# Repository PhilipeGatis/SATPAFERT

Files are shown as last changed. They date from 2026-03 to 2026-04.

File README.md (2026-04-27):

<p align="center">
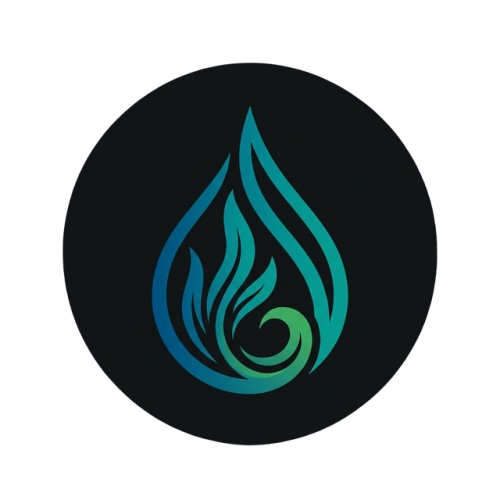
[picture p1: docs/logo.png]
IARA Logo
  
</p>

# IARA

**Automated Water Change, Fertilization & Filtration System for Aquariums** — ESP32 firmware.

*Named after Iara, the freshwater spirit from Brazilian folklore.*



> 🇧🇷 Leia em português: [README.pt-BR.md](README.pt-BR.md)
>
> 🇯🇵 日本語で読む: [README.ja.md](README.ja.md)

---

## 📖 About

**IARA** is a complete embedded system for planted aquarium automation. It manages:

- **Water Change (TPA)** — automated drain & refill with a 6-state state machine.
- **Fertilization** — scheduled dosing via peristaltic pumps with stock tracking.
- **Filtration** — canister on/off control through an SSR relay (AC power).
- **Safety** — continuous sensor monitoring, watchdog timer, and emergency shutdown mode.

The firmware runs on an **ESP32 DevKit V1** and features an **embedded web dashboard** (React + Vite served via LittleFS), **color TFT display (ST7735)**, **DS3231 RTC clock**, and a **serial command interface**.

---

## 📚 Additional Documentation

The project includes detailed hardware documentation in the following files:

| Document | Description |
|---|---|
| [`BOM.md`](BOM.md) | **Bill of Materials** — complete list of all components required for assembly, organized by layer (AC, DC, actuators, sensors, protection, and connectors), with specifications and quantities. |
| [`HARDWARE.md`](HARDWARE.md) | **Hardware Architecture** — detailed technical documentation with wiring diagrams for each layer (AC input, DC bus, and peripherals), including noise protection schemes, voltage dividers for sensors, and safety implementation notes. |
| [`3d_models/`](3d_models/) | **3D Models (OpenSCAD)** — parametric electronics enclosure (`electronics_enclosure.scad`) with full module layout, dosing pump supports (`dosing_pump_support.scad` / `dosing_pump_single.scad`), and drill test plate for verification. |

---

## 🏗️ Firmware Architecture

```
main.cpp               ← Main orchestrator
├── SafetyWatchdog      ← Sensors + emergency + maintenance mode
├── TimeManager         ← DS3231 RTC + NTP sync
├── FertManager         ← Dosing + NVS dedup + stock tracking
├── WaterManager        ← Water change state machine (6 states)
├── DisplayManager      ← TFT ST7735 128×160 (SPI)
└── WebManager          ← Embedded web dashboard + serial interface
```

### Safety-First Loop

```cpp
loop() {
    safety.update();          // 🔴 Highest priority
    if (emergency) return;
    timeMgr.update();
    commands.process();
    schedules.check();
    waterMgr.update();        // Water change state machine
    telemetry.send();
}
```

### 🔄 Water Change (TPA) Flow

The TPA is a 6-state state machine that runs non-blocking inside the main loop. Each state has a configurable timeout for safety.

```mermaid
stateDiagram-v2
    [*] --> CANISTER_OFF: startTPA()
    CANISTER_OFF --> DRAINING: 3s settle
    DRAINING --> FILLING_RESERVOIR: level reached
    FILLING_RESERVOIR --> DOSING_PRIME: float switch
    DOSING_PRIME --> REFILLING: 2s mix
    REFILLING --> CANISTER_ON: level reached
    CANISTER_ON --> [*]: COMPLETE

    DRAINING --> ERROR: timeout
    FILLING_RESERVOIR --> ERROR: timeout
    REFILLING --> ERROR: timeout / optical sensor
    ERROR --> [*]: check level → canister ON/OFF
```

| Step | State | What happens |
|---|---|---|
| 1 | **CANISTER_OFF** | Canister filter is turned off (SSR relay HIGH). Waits 3 seconds for water to settle so the ultrasonic sensor gets a stable reading. |
| 2 | **DRAINING** | Drain pump turns on. Ultrasonic sensor monitors the water level. Pump runs until the target level is reached (e.g. 10 cm drop). Flow rate is measured inline for auto-calibration. |
| 3 | **FILLING_RESERVOIR** | Solenoid valve opens to fill the reservoir with tap water. Float switch monitors reservoir level. Valve closes when reservoir is full. |
| 4 | **DOSING_PRIME** | Peristaltic pump doses dechlorinator (Prime) into the reservoir. Waits 2 seconds for mixing. Stock level is deducted and saved to NVS. |
| 5 | **REFILLING** | Refill pump turns on, pumping treated water from reservoir into the aquarium. Stops when ultrasonic sensor reaches the original level OR optical sensor detects max level (safety cutoff). Flow rate is measured for calibration. |
| 6 | **CANISTER_ON** | Canister filter is turned back on. **TPA cycle complete.** Calibrated flow rates are saved to NVS for next TPA. |

**Safety at every step:**
- Each state has a **dynamic timeout** calculated from calibrated flow rates (`volume / flow × 1.5`). First TPA uses safe defaults: **30s drain, 15s refill**.
- The **optical sensor** acts as a hardware-level safety cutoff during refill — immediate stop regardless of ultrasonic reading.
- **Emergency abort** at any point turns off all actuators and restores the canister filter.
- **On error**, the system checks the water level via ultrasonic before turning the canister back on. If the level is too low (e.g. error during drain), the canister **stays OFF** to avoid running dry and damaging the pump.

---

## 🔌 Hardware Overview

### Main Connections

```mermaid
graph LR
  subgraph Power [⚡ 12V & 5V]
    PSU[12V PSU] -->|12V| MOSFET[8-Channel MOSFET Module]
    PSU -->|12V| LM2596[LM2596 Step Down]
    LM2596 -->|5V| Cap[Electrolytic Capacitor]
    Cap -->|5V| ESP32[ESP32 VIN]
    Cap -->|5V VCC| SENS[Sensors]
  end

  subgraph Signals [🎮 ESP32 Signals]
    ESP32 -->|D21 SDA, D22 SCL| I2C[RTC DS3231]
    ESP32 -->|SPI D15,16,17,23| TFT[TFT Display ST7735]
    ESP32 -->|D12, D13, D14, D25-D27, D32, D33| MOSFET
    ESP32 -->|D2| SSR[Omron SSR]
    ESP32 ---|D18 Trig, D34 Echo| Ultra[Ultrasonic JSN]
    ESP32 ---|D4| Water[Capacitive Sensor]
    ESP32 ---|D5| Float[Float Switch]
    ESP32 ---|D19| Button[Button]
  end

  MOSFET -->|OUT 1–5| Peristaltic[5x Peristaltic Pumps]
  MOSFET -->|OUT 6| Drain[Drain Pump]
  MOSFET -->|OUT 7| Refill[Refill Pump]
  MOSFET -->|OUT 8| Solenoid[Solenoid Valve]
```

> For detailed wiring diagrams, voltage dividers, and protection notes (flyback diodes, star GND), see [`HARDWARE.md`](HARDWARE.md).
>
> For the complete component list and quantities, see [`BOM.md`](BOM.md).

### ESP32 GPIO Connection Diagram

| GPIO | Function | Component | Direction | Protocol |
|---|---|---|---|---|
| **D2** | Canister ON/OFF | Omron SSR Relay | Output | Digital |
| **D4** | Max level sensor | XKC-Y25-NPN (capacitive) | Input (PULLUP) | Digital |
| **D5** | Reservoir float | Horizontal Float Switch | Input (PULLUP) | Digital |
| **D12** | Fertilizer CH2 | MOSFET channel 2 | Output | Digital |
| **D13** | Fertilizer CH1 | MOSFET channel 1 | Output | Digital |
| **D14** | Fertilizer CH3 | MOSFET channel 3 | Output | Digital |
| **D15** | TFT CS | ST7735 Display (CS) | Output | SPI (CS) |
| **D16** | TFT SCK | ST7735 Display (SCK) | Output | SPI (SCK) |
| **D17** | TFT A0 (Data/Command) | ST7735 Display (A0) | Output | SPI (DC) |
| **D18** | Ultrasonic Trigger | JSN-SR04T | Output | Digital |
| **D19** | Contact button | Push/Tactile Button (Panel) | Input (PULLUP) | Digital |
| **D21** | SDA | DS3231 RTC | Bidirectional | I2C |
| **D22** | SCL | DS3231 RTC | Bidirectional | I2C |
| **D23** | TFT SDA (Data) | ST7735 Display (SDA) | Output | SPI (MOSI) |
| **D25** | Drain pump | MOSFET channel 6 | Output | Digital |
| **D26** | Prime (dechlorinator) | MOSFET channel 5 | Output | Digital |
| **D27** | Fertilizer CH4 | MOSFET channel 4 | Output | Digital |
| **D32** | Solenoid valve | MOSFET channel 8 | Output | Digital |
| **D33** | Refill pump | MOSFET channel 7 | Output | Digital |
| **D34** | Ultrasonic Echo | JSN-SR04T | Input | Digital (3.3V via divider) |
| **VIN** | 5V Power | LM2596 step-down | — | Power |
| **EN** | Shared reset | ST7735 Display (RESET) | — | Reset |
| **3.3V** | Backlight | ST7735 Display (LED) | — | Power |

---

## 🛡️ Safety & Reliability

The system is designed with a **safety-first** approach to prevent flooding, equipment damage, and fish loss.

### Software Protections

| Protection | Description |
|---|---|
| **Hardware Watchdog (WDT)** | ESP32 Task WDT with 10-second timeout. If the main loop freezes for any reason, the ESP32 automatically reboots. |
| **SafetyWatchdog** | Runs at highest priority every loop iteration. Detects overflow (optical sensor), emergency conditions, and triggers full shutdown of all actuators. |
| **Non-blocking loops** | All wait states (canister settle, prime mixing) use `millis()` instead of `delay()`, so the safety watchdog keeps running during waits. |
| **State machine timeouts** | Each TPA state (`DRAINING`, `FILLING`, `REFILLING`) has a configurable timeout. Exceeding it triggers an error state and shuts down all actuators. |
| **NVS deduplication** | Prevents double-dosing fertilizers on the same day, even after unexpected reboots. |
| **Emergency shutdown** | `emergency_stop` command turns off ALL actuators immediately. |
| **CPU throttle** | Main loop runs at ~100 Hz (`delay(10)`), preventing overheating and leaving CPU headroom for WiFi/TCP stack. |
| **Pump auto-calibration** | Flow rates measured inline during TPA (Δlevel × litersPerCm / Δtime). Dynamic timeouts = `(volume / flow) × 1.5`. First TPA uses safe 30s/15s defaults. |
| **Mandatory TPA config** | TPA will not start unless all required parameters are configured: aquarium dimensions, reservoir volume, drain %, and canister safe level %. Prevents running with invalid/default values. |
| **Canister safe level (%)** | Configurable minimum water level (as % of aquarium height) required to safely turn the canister back on after a TPA error. If the water is below this threshold (e.g. error during drain), the canister stays OFF to prevent running dry. |

### Hardware Recommendations

| Protection | Description |
|---|---|
| **Overflow float switch** | NC (normally closed) float switch at max water level, wired in series with the refill pump power. Cuts the pump physically if water rises too high — independent of firmware. |
| **Flyback diodes** | FR154 on pumps, 1N5822 on solenoid — absorb voltage spikes from inductive loads. |
| **Decoupling capacitors** | 1000µF near ESP32, 470µF near MOSFET module — absorb brownout transients. |
| **Voltage divider (ECHO)** | 5V → 3.3V for JSN-SR04T echo pin — protects ESP32 GPIO. |
| **Siphon break (Drain)** | Wire a solenoid valve in parallel with the drain pump (requires its own flyback diode) or make a small breather hole in the hose inside the aquarium to prevent water from continuing to drain by gravity after the pump turns off. |

---

## 📲 Push Notifications

IARA sends real-time push notifications to your phone via [Pushsafer](https://www.pushsafer.com/). Each notification type can be individually enabled or disabled via the dashboard.

### Notification Types

| Type | Trigger | Example Message |
|---|---|---|
| **TPA Complete** | Water change finished successfully | `✅ TPA completed successfully` |
| **TPA Error** | Timeout or failure during TPA | `⚠️ Drain timeout \| Canister: OFF (nivel 45%, min: 60%)` |
| **Fert Low Stock** | Fertilizer stock below threshold | `⚠️ CH1 Potássio: 15 mL remaining (threshold: 50 mL)` |
| **Emergency** | Emergency shutdown triggered | `🚨 Emergency shutdown activated!` |
| **Fert Complete** | Fertilizer dose completed | `💧 CH2 dosed 5.0 mL` |
| **Daily Level** | Scheduled daily water level report | `📊 Water level: 12.3 cm` |

### Rate Limiting

| Parameter | Value |
|---|---|
| Cooldown per type | 5 minutes (same type won't fire twice) |
| Max per day | 20 notifications total |
| Daily counter reset | Midnight (auto) |

### Setup

1. Create a free account at [pushsafer.com](https://www.pushsafer.com/)
2. Copy your **Private Key** from the Pushsafer dashboard
3. Enter the key via IARA dashboard (`Notifications → API Key`) or via API:
   ```bash
   curl -X POST http://<ESP32_IP>/api/notify/key -d '{"key":"YOUR_KEY"}'
   ```
4. Enable/disable specific notification types via the dashboard

---

## ⚙️ System Configuration

Before the first TPA can run, the system requires all safety-critical parameters to be configured. This ensures the water change operates safely for your specific aquarium setup.

### Required Parameters (Mandatory for TPA)

| Parameter | API Field | Description |
|---|---|---|
| **Aquarium Height** | `aqHeight` | Internal height in cm |
| **Aquarium Length** | `aqLength` | Internal length in cm |
| **Aquarium Width** | `aqWidth` | Internal width in cm |
| **Reservoir Volume** | `reservoirVolume` | Reservoir capacity in liters |
| **TPA Drain %** | `tpaPercent` | Percentage of aquarium volume to drain (e.g. 30%) |
| **Canister Safe Level %** | `canisterSafePct` | Minimum water % required to safely turn canister ON (e.g. 60%) |

> [!IMPORTANT]
> TPA will **not start** until all 6 parameters above are configured. The dashboard shows `tpaConfigReady: true/false` to indicate readiness.

### Optional Parameters

| Parameter | API Field | Description |
|---|---|---|
| **Water Margin** | `aqMarginCm` | Distance from top edge to water surface (cm) |
| **Prime Ratio** | `primeRatio` | mL of dechlorinator per liter of water |
| **Reservoir Safety** | `reservoirSafetyML` | Minimum mL to keep in reservoir for pump safety |
| **TPA Interval** | `tpaInterval` | Days between automatic TPAs (e.g. 7) |
| **TPA Schedule** | `tpaHour`, `tpaMinute` | Time of day for automatic TPA |

### Configuration via API

**Aquarium dimensions:**
```bash
curl -X POST http://<ESP32_IP>/api/config/aquarium \
  -H "Content-Type: application/json" \
  -d '{"aqHeight":45, "aqLength":90, "aqWidth":40, "aqMarginCm":3, "reservoirVolume":20, "primeRatio":0.5}'
```

**TPA schedule + canister safety:**
```bash
curl -X POST http://<ESP32_IP>/api/schedule \
  -H "Content-Type: application/json" \
  -d '{"tpaInterval":7, "tpaHour":10, "tpaMinute":0, "tpaPercent":30, "canisterSafePct":60}'
```

### How Configuration is Stored

All parameters are persisted in **NVS (Non-Volatile Storage)** and survive reboots and power cycles. Configuration can be set via:

1. **Web Dashboard** — React SPA with forms for all parameters
2. **REST API** — JSON endpoints for programmatic access
3. **Serial Commands** — USB serial for debugging and initial setup

### Derived Values (Auto-Calculated)

| Value | Formula | Purpose |
|---|---|---|
| **Aquarium Volume** | `(Height - Margin) × Length × Width / 1000` | Total water volume in liters |
| **Liters per cm** | `Length × Width / 1000` | Volume change per cm of water level |
| **Prime dose** | `Reservoir Volume × Prime Ratio` | Auto-calculated dechlorinator dose |
| **Drain cm** | `(Volume × TPA%) / Liters per cm` | Calculated at TPA start |
| **Canister safe cm** | `EffHeight × (100 - SafePct) / 100` | Ultrasonic distance threshold |
| **Dynamic timeouts** | `(Volume / Flow) × 1.5` | Calculated from calibrated flow rates |

---

---

## 🧪 Testing

### Run unit tests (no hardware required)

```bash
pio test -e native
```

### Generate coverage report

```bash
pio test -e coverage && ./scripts/coverage.sh
open coverage/index.html
```

### Test Suites

| Suite | Tests | Coverage |
|---|---|---|
| `test_fert_manager` | 13 | NVS dedup, stock, GPIO, persistence |
| `test_safety_watchdog` | 14 | Sensors, emergency, maintenance |
| `test_water_manager` | 23 | Full water change state machine + calibration |
| `test_time_manager` | 15 | DateTime, scheduling, formatting |
| `test_notify_manager` | 10 | Notifications, formatting |

### 📊 Code Coverage

| File | Coverage |
|---|---|
| `WaterManager.cpp` | 92% |
| `SafetyWatchdog.cpp` | 81% |
| `FertManager.cpp` | 75% |
| `NotifyManager.cpp` | 43% |
| **Total** | **75%** |

> 75 native unit tests running in CI on every commit.

---

## 🚀 Build & Deploy

### Build and flash firmware

```bash
# Build firmware
pio run

# Flash to ESP32
pio run --target upload

# Serial monitor
pio device monitor
```

### Full deploy (Frontend + Firmware)

The `Makefile` automates the full workflow:

```bash
# All at once: build React → upload LittleFS → flash firmware
make all

# Or individual steps:
make build-front     # Build React app (Vite)
make upload-fs       # Upload static files to LittleFS
make upload-fw       # Build and flash C++ firmware
make monitor         # Open serial monitor
make clean           # Clean all builds
```

### Frontend (Web Dashboard)

The web dashboard is a React + Vite + Tailwind CSS SPA located in `frontend/`. After building, static files are copied to `data/` and uploaded to the ESP32 via LittleFS.

```bash
cd frontend && npm install && npm run build
```

---

## ⌨️ Serial Commands

| Command | Description |
|---|---|
| `help` | List available commands |
| `status` | Current system state |
| `tpa` | Start manual water change |
| `abort` | Abort water change in progress |
| `maint` | Toggle maintenance mode (30 min) |
| `fert_time HH MM` | Set fertilization time |
| `tpa_time DOW HH MM` | Set water change schedule |
| `dose CH ML` | Set dose for channel CH (1–5) |
| `reset_stock CH ML` | Reset stock for channel CH |
| `set_drain CM` | Set drain target level |
| `set_refill CM` | Set refill target level |
| `emergency_stop` | Shut down ALL actuators |

---

## 📁 Project Structure

```
├── BOM.md                    # Bill of Materials (pt-BR)
├── BOM.en.md                 # Bill of Materials (en-US)
├── BOM.ja.md                 # Bill of Materials (ja-JP)
├── HARDWARE.md               # Hardware architecture (pt-BR)
├── 3d_models/                # 3D models for printing and laser cutting
│   ├── electronics_enclosure.scad  # Electronics enclosure (base + lid)
│   ├── dosing_pump_support.scad    # 8-pump dosing support
│   └── dosing_pump_single.scad     # Single pump support
├── HARDWARE.en.md            # Hardware architecture (en-US)
├── HARDWARE.ja.md            # Hardware architecture (ja-JP)
├── README.md                 # Documentation (en-US) — default
├── README.pt-BR.md           # Documentation (pt-BR)
├── README.ja.md              # Documentation (ja-JP)
├── Makefile                  # Automation: build frontend + upload
├── platformio.ini            # Environments: esp32dev, native, coverage
├── include/
│   ├── Config.h              # Pins, timeouts, constants
│   ├── SafetyWatchdog.h
│   ├── TimeManager.h
│   ├── FertManager.h
│   ├── WaterManager.h
│   ├── WebManager.h
│   └── web_dashboard.h       # Dashboard HTML/CSS/JS (fallback)
├── src/
│   ├── main.cpp              # Setup + loop
│   ├── SafetyWatchdog.cpp
│   ├── TimeManager.cpp
│   ├── FertManager.cpp
│   ├── WaterManager.cpp
│   └── WebManager.cpp
├── frontend/                 # React + Vite + Tailwind dashboard
│   ├── src/
│   └── vite.config.ts
├── data/                     # Static files (frontend build → LittleFS)
├── test/
│   ├── mocks/                # Arduino mock layer (GPIO, NVS, RTC)
│   ├── test_fert_manager/
│   ├── test_safety_watchdog/
│   ├── test_water_manager/
│   └── test_time_manager/
├── scripts/
│   └── coverage.sh           # lcov coverage report generator
└── .github/workflows/
    └── test.yml              # CI: tests on every commit
```

---

## ☕ Support

If you find this project helpful, consider buying me a coffee!

<a href="https://buymeacoffee.com/iara.automatedwaterchange" target="_blank">
  Buy Me A Coffee
</a>

---

## 📜 License

MIT

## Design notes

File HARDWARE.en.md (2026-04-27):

# Hardware Architecture Documentation: Aquarium Management System

## 📋 Overview

The system uses a **Defense in Depth** topology with noise filtering at the input (AC), stabilization on the main bus (DC), and inductive spike suppression at the edge (Actuators).

```
┌─────────────────────┐     ┌─────────────────────┐     ┌─────────────────────┐
│  LAYER 1: AC        │ ──► │  LAYER 2: DC        │ ──► │  LAYER 3: EDGE      │
│  Input/Protection   │     │  Bus/Logic          │     │  Peripherals/Suppr. │
│                     │     │                     │     │                     │
│  • AC Fuse          │     │  • 12.53V PSU       │     │  • Flyback Diodes   │
│  • NTC (Inrush)     │     │  • LM2596 → 5.1V    │     │  • Decoupling Caps  │
│  • EMI Filter (Y)   │     │  • Cap Bank         │     │  • Sensors (GX12)   │
│  • Canister Relay   │     │  • 8-Ch MOSFET      │     │  • Pumps + Valve    │
└─────────────────────┘     └─────────────────────┘     └─────────────────────┘
```

---

## ⚡ Layer 1: AC Input & Protection (Infrastructure)

The power input architecture focuses on simplicity and maximum electrical safety, delegating heavy filtering (like EMI filter and NTC/Inrush limits) to the professional circuits already built into the Switching Power Supply.

### Components

| Component | Function |
|---|---|
| **AC Glass Fuse** (3A to 5A) | Mandatory item: Protection against hard short circuits and fire risks |
| **SSR Relay Module 1CH** | Independent control via ESP32 for the Canister filter (AC) |

### Wiring Diagram

```text
[ IEC C14 INLET ]
      │
      ├─── [ GROUND PIN (Green) ] ────────┬───────► [ PSU GROUND (G) Terminal ]
      │                                   │
      │                                   └───────► [ Canister Outlet GROUND ]
      │         
      ├─── [ NEUTRAL PIN (Blue) ] ────────┬───────► [ PSU NEUTRAL (N) Terminal ]
      │                                   │
      │                                   └───────► [ Canister Outlet NEUTRAL ]
      │
      └─── [ LIVE PIN (Brown) ] ─── [ FUSE ] ─────┐
                                                  │
             ┌────────────────────────────────────┘
             │                                  
             ├───────────────────► [ PSU LIVE (L) Terminal ]
             │
             └───► [ SSR Relay Screw 1 ] ── SWITCH ──► [ SSR Relay Screw 2 ] ──► [ Canister Outlet LIVE ]
```

---

## 🔋 Layer 2: DC Bus & Logic (Distribution)

Responsible for converting power to logic levels and maintaining ESP32 stability during heavy load switching.

### Components

| Component | Function |
|---|---|
| **180W Switching PSU** | Adjusted to 12.53V |
| **T5AL250V Fuse** | Physical firewall for 8 pumps and sensors |
| **LM2596** | Step-down adjusted to 5.1V (ESP32 power) |
| **1× 470µF 16V** | In parallel at 12V MOSFET input (Prevents voltage dips on pump startup) |
| **4× 1000µF 10V** | In parallel at 5V output (Acts as a "UPS" for ESP32 to withstand line fluctuations and spikes) |

### Wiring Diagram

```text
[ PSU 12.53V ]
   │              │
 (V+)           (V─) ──────────────────────────────┐ (STAR GND)
   │              │                                │
[T5A FUSE]        │                                │
   │              │                                │
   ├──────────────┼────────────────┐               │
   │              │                │               │
[LM2596 IN+]  [LM2596 IN─]    [MOSFET VIN]   [MOSFET GND]
   │              │                │               │
(Output 5.1V)     │         (1× 470µF 16V)         │
   │              │                │               │
(4× 1000µF 10V)   │                │               │
   │              │                │               │
[ESP32 VIN]   [ESP32 GND]          │               │
   │              │         [ 8-CH MOSFET ]        │
   │              └────────────────┴───────────────┘
```

> [!IMPORTANT]
> **Star GND**: All negative references must return directly to the PSU V− terminal to avoid ground loops.

---

## 🌊 Layer 3: Peripherals & Suppression (Edge)

Responsible for mitigating inductive noise (Flyback) and stabilizing sensor readings on long cables (1.2m).

### Components

| Component | Application | Qty |
|---|---|---|
| **FR154 Diodes** (Fast Recovery) | Refill and Drain Pumps | 2 |
| **FR154 Diodes** (Fast Recovery) | Peristaltic Pumps (4 Fert + 1 Prime) | 5 |
| **1N5822 Diode** (Schottky) | Solenoid Valve (Channel 8) | 1 |
| **10µF / 22µF 50V Capacitors** | Sensor decoupling at cable ends (GX12) | — |

> [!NOTE]
> **Total: 8 flyback diodes** — one per motor channel (7× FR154 + 1× 1N5822). All installed at the cable end, next to the motor.

### Wiring Diagram — Actuators

```
[ MOSFET CHANNEL ] ──────────── (1.2m Wire) ──────┬────────── (PUMP +)
                                                   │
                                             [ FLYBACK DIODE ]
                                             (Stripe on POS+)
                                                   │
[ BUS GND ] ─────────────────── (1.2m Wire) ───────┴────────── (PUMP ─)
```

> [!CAUTION]
> **Flyback Diodes**: Must be installed at the **cable end** (next to the motor) to prevent the 1.2m cable from radiating noise like an antenna.

### Wiring Diagram — Ultrasonic Sensor (JSN-SR04T)

The sensor operates at 5V, but the ESP32 supports a maximum of **3.3V** on GPIOs. The **ECHO** pin requires a resistive voltage divider to reduce 5V → 3.3V before entering GPIO34.

| Component | Function |
|---|---|
| **1kΩ Resistor** (R1) | In series between ECHO and GPIO34 |
| **2kΩ Resistor** (R2) | Pull-down between GPIO34 and GND |

**Formula:** `Vout = 5V × R2 / (R1 + R2) = 5 × 2k / 3k = 3.33V` ✅

```
                           ┌──────────────────┐
  ESP32 GPIO18 (TRIG) ─────┤ TRIG    JSN-SR04T│
                           │                  │
  ESP32 5V ────────────────┤ VCC              │
                           │                  │
  GND ─────────────────────┤ GND              │
                           │                  │
                           │ ECHO ────┐       │
                           └──────────┼───────┘
                                      │
                                 [ R1 = 1kΩ ]
                                      │
                    ESP32 GPIO34 ──────┤
                                      │
                                 [ R2 = 2kΩ ]
                                      │
                                    (GND)
```

> [!WARNING]
> **Never connect ECHO directly to the ESP32** without the voltage divider. The 5V ECHO signal can permanently damage the ESP32 GPIO.

### Wiring Diagram — Capacitive Level Sensor (XKC-Y25-NPN)

Non-contact sensor that detects liquid presence through glass/tube walls. NPN open-collector output, directly compatible with ESP32's 3.3V.

| Sensor Pin | Connection |
|---|---|
| **VCC** (red) | ESP32 3.3V |
| **GND** (black) | GND |
| **OUT** (yellow) | GPIO 4 (`INPUT_PULLUP`) |

```
  ESP32 3.3V ─────────── VCC (red)
                                            ┌────────────────┐
  ESP32 GPIO4 ─────────── OUT (yellow) ────┤ XKC-Y25-NPN    │
   (INPUT_PULLUP)                          │ (glued on the  │
                                            │  outside of    │
  GND ─────────────────── GND (black)  ────┤  glass/tube)   │
                                            └────────────────┘
```

> [!TIP]
> **No external resistor needed.** The ESP32's internal pull-up (~45kΩ) is sufficient for the NPN open-collector. The sensor is glued to the **outside** of the aquarium glass at the desired maximum level.

### Wiring Diagram — TFT ST7735 Display (SPI)

1.8" color display, 128×160 pixels. Operates at **3.3V** — incompatible with 5V. Uses software SPI (bit-banging) on custom pins.

| Display Pin | ESP32 Connection | GPIO | Notes |
|---|---|---|---|
| **VCC** | 3.3V | — | ⚠️ Never use 5V |
| **GND** | GND | — | |
| **CS** | D15 | GPIO15 | Chip Select |
| **RESET** | EN pin | — | Hardware reset shared with ESP32 |
| **A0 (DC)** | TX2 | GPIO17 | Data/Command |
| **SDA (MOSI)** | D23 | GPIO23 | SPI Data |
| **SCK** | RX2 | GPIO16 | SPI Clock |
| **LED** | 3.3V | — | Fixed backlight (no free GPIO available) |

```
ESP32 3.3V  ────►  VCC
ESP32 GND   ────►  GND
ESP32 D15   ────►  CS
ESP32 EN    ────►  RESET
ESP32 TX2   ────►  A0 (DC)
ESP32 D23   ────►  SDA (MOSI)
ESP32 RX2   ────►  SCK
ESP32 3.3V  ────►  LED (fixed backlight)
```

> [!WARNING]
> The display **RESET** pin must connect to the ESP32 **EN** pin (not a GPIO). This ensures the display resets together with the microcontroller. With EN HIGH (normal operation), the display works normally.

> [!NOTE]
> On the ESP32 DevKit V1 breakout board, **D16** and **D17** are labeled **RX2** and **TX2** respectively. Use your terminal block labels to identify the correct positions.

---

### Wiring Diagram — Navigation Button

Physical button that controls the display: short press cycles pages; long press opens the menu (start TPA or toggle maintenance mode).

| Pin | Connection | GPIO | Configuration |
|---|---|---|---|
| **Terminal 1** | GPIO19 | GPIO19 | `INPUT_PULLUP` — active LOW |
| **Terminal 2** | GND | — | |

```
ESP32 GPIO19 ─────── [ BUTTON ] ──── GND
         INPUT_PULLUP, active LOW (pressed = LOW)
```

> [!TIP]
> The button can be mounted on the panel using a standard push-button or tactile switch. The firmware detects **short press** (page change) and **long press > 1s** (opens menu).

---

## 🛠️ Safe Implementation Notes

1. **AC Connections** — Insulate all 110V/220V solder joints and connections with heat-shrink tubing for maximum safety.

2. **Capacitor Polarity** — Check the negative stripe on all electrolytics (especially the 1000µF 10V operating at 5.1V).

3. **Flyback Diodes** — Must be installed at the cable end (next to the motor) to prevent the 1.2m cable from radiating noise like an antenna.

4. **Star GND** — All negative references must return directly to the PSU V− terminal to avoid ground loops.

5. **Siphon Effect (Hydraulics)** — To prevent continuous gravity draining of the aquarium after the drain pump is turned off, wire a solenoid valve in parallel with the drain pump (on the same MOSFET channel, ensuring a flyback diode for each) or make a breather hole in the hose.

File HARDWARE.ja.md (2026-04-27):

# ハードウェアアーキテクチャ資料：水槽管理システム

## 📋 概要

本システムは**多層防御**トポロジーを採用し、入力側（AC）でのノイズフィルタリング、メインバス（DC）での安定化、エッジ側（アクチュエーター）での誘導性スパイク抑制を行います。

```
┌─────────────────────┐     ┌─────────────────────┐     ┌─────────────────────┐
│ レイヤー1: AC        │ ──► │ レイヤー2: DC        │ ──► │ レイヤー3: エッジ    │
│ 入力/保護           │     │ バス/ロジック       │     │ 周辺機器/抑制       │
│                     │     │                     │     │                     │
│ • ACヒューズ        │     │ • 12.53V電源        │     │ • フライバックD     │
│ • NTC（突入電流）   │     │ • LM2596 → 5.1V    │     │ • デカップリングC   │
│ • EMIフィルタ（Y）  │     │ • コンデンサバンク  │     │ • センサー（GX12）  │
│ • キャニスターリレー│     │ • 8ch MOSFET        │     │ • ポンプ + バルブ   │
└─────────────────────┘     └─────────────────────┘     └─────────────────────┘
```

---

## ⚡ レイヤー1：AC入力・保護（インフラストラクチャ）

電力入力アーキテクチャはシンプルさと最大限の電気的安全性を重視し、重いフィルタリング（EMIフィルターやNTC/突入電流制限など）は、スイッチング電源にすでに組み込まれているプロ用回路に委ねています。

### コンポーネント

| コンポーネント | 機能 |
|---|---|
| **ACガラス管ヒューズ**（3A〜5A） | 必須項目：短絡および火災リスクに対する保護 |
| **SSRリレーモジュール 1CH** | キャニスターフィルター独立制御（ESP32経由、AC） |

### 配線図

```text
[ IEC C14 入力 ]
      │
      ├─── [ 接地ピン (緑) ] ─────────────────┬───► [ 電源 接地 (G) 端子 ]
      │                                       │
      │                                       └───► [ キャニスター出力 接地ピン ]
      │         
      ├─── [ 中性ピン (青) ] ─────────────────┬───► [ 電源 中性 (N) 端子 ]
      │                                       │
      │                                       └───► [ キャニスター出力 中性ピン ]
      │
      └─── [ 相ピン (茶) ] ───── [ ヒューズ ] ──┐
                                                │
             ┌──────────────────────────────────┘
             │                                  
             ├───────────────────► [ 電源 相 (L) 端子 ]
             │
             └───► [ SSRリレー ネジ1 ] ── スイッチ ──► [ SSRリレー ネジ2 ] ──► [ キャニスター出力 相ピン ]
```

---

## 🔋 レイヤー2：DCバス・ロジック（分配）

電力をロジックレベルに変換し、重負荷スイッチング時のESP32安定性を維持します。

### コンポーネント

| コンポーネント | 機能 |
|---|---|
| **スイッチング電源 180W** | 12.53Vに調整 |
| **ヒューズ T5AL250V** | 8台のポンプとセンサーの物理的保護 |
| **LM2596** | 5.1Vに調整されたステップダウン（ESP32電源） |
| **1× 470µF 16V** | MOSFETの12V入力に並列（ポンプ起動時の電圧降下を防止） |
| **4× 1000µF 10V** | 5V出力に並列（ESP32のスパイクや変動対策、「無停電電源」として安定動作を保証） |

### 配線図

```text
[ 電源 12.53V ]
   │              │
 (V+)           (V─) ──────────────────────────────┐ (スターGND)
   │              │                                │
[T5Aヒューズ]     │                                │
   │              │                                │
   ├──────────────┼────────────────┐               │
   │              │                │               │
[LM2596 IN+]  [LM2596 IN─]    [MOSFET VIN]   [MOSFET GND]
   │              │                │               │
(出力 5.1V)       │         (1× 470µF 16V)         │
   │              │                │               │
(4× 1000µF 10V)   │                │               │
   │              │                │               │
[ESP32 VIN]   [ESP32 GND]          │               │
   │              │          [ 8ch MOSFET ]        │
   │              └────────────────┴───────────────┘
```

> [!IMPORTANT]
> **スターGND**：全ての負側基準は電源のV−端子に直接戻し、グランドループを防止してください。

---

## 🌊 レイヤー3：周辺機器・抑制（エッジ）

誘導性ノイズ（フライバック）の軽減および長距離ケーブル（1.2m）でのセンサー読み取り安定化を担当します。

### コンポーネント

| コンポーネント | 用途 | 数量 |
|---|---|---|
| **FR154ダイオード**（高速リカバリ） | 給排水ポンプ | 2 |
| **FR154ダイオード**（高速リカバリ） | ペリスタルティックポンプ（肥料4 + プライム1） | 5 |
| **1N5822ダイオード**（ショットキー） | ソレノイドバルブ（チャンネル8） | 1 |
| **10µF / 22µF 50Vコンデンサ** | ケーブル端でのセンサーデカップリング（GX12） | — |

> [!NOTE]
> **合計：8個のフライバックダイオード** — モーターチャンネルごとに1個（7× FR154 + 1× 1N5822）。すべてケーブル端のモーター近傍に設置。

### 配線図 — アクチュエーター

```
[ MOSFETチャンネル ] ──────── (1.2mワイヤ) ──────┬────────── (ポンプ +)
                                                 │
                                           [ フライバックD ]
                                           (ストライプは+側)
                                                 │
[ バスGND ] ─────────────── (1.2mワイヤ) ────────┴────────── (ポンプ ─)
```

> [!CAUTION]
> **フライバックダイオード**：必ず**ケーブル端**（モーター近傍）に設置してください。1.2mケーブルがアンテナのようにノイズを放射するのを防ぎます。

### 配線図 — 超音波センサー（JSN-SR04T）

センサーは5Vで動作しますが、ESP32のGPIOは最大**3.3V**です。**ECHO**ピンにはGPIO34に入力する前に5V → 3.3Vに降下させる分圧回路が必要です。

| コンポーネント | 機能 |
|---|---|
| **1kΩ抵抗**（R1） | ECHOとGPIO34の間に直列 |
| **2kΩ抵抗**（R2） | GPIO34とGND間のプルダウン |

**計算式：** `Vout = 5V × R2 / (R1 + R2) = 5 × 2k / 3k = 3.33V` ✅

```
                           ┌──────────────────┐
  ESP32 GPIO18 (TRIG) ─────┤ TRIG    JSN-SR04T│
                           │                  │
  ESP32 5V ────────────────┤ VCC              │
                           │                  │
  GND ─────────────────────┤ GND              │
                           │                  │
                           │ ECHO ────┐       │
                           └──────────┼───────┘
                                      │
                                 [ R1 = 1kΩ ]
                                      │
                    ESP32 GPIO34 ──────┤
                                      │
                                 [ R2 = 2kΩ ]
                                      │
                                    (GND)
```

> [!WARNING]
> **ECHOを分圧回路なしでESP32に直接接続しないでください。**5VのECHO信号はESP32のGPIOを永久に損傷する可能性があります。

### 配線図 — 静電容量式水位センサー（XKC-Y25-NPN）

ガラス/チューブ壁越しに液体の存在を検知する非接触センサー。NPN オープンコレクタ出力、ESP32の3.3Vと直接互換性があります。

| センサーピン | 接続先 |
|---|---|
| **VCC**（赤） | ESP32 3.3V |
| **GND**（黒） | GND |
| **OUT**（黄） | GPIO 4（`INPUT_PULLUP`） |

```
  ESP32 3.3V ─────────── VCC（赤）
                                            ┌────────────────┐
  ESP32 GPIO4 ─────────── OUT（黄） ───────┤ XKC-Y25-NPN    │
   (INPUT_PULLUP)                          │ （ガラス外側   │
                                            │  に貼付）      │
  GND ─────────────────── GND（黒） ───────┤                │
                                            └────────────────┘
```

> [!TIP]
> **外部抵抗は不要。**ESP32の内部プルアップ（約45kΩ）でNPNオープンコレクタに十分です。センサーは水槽ガラスの**外側**、希望する最大水位に貼り付けます。

### 配線図 — TFT ST7735ディスプレイ (SPI)

1.8インチカラーディスプレイ、128×160ピクセル。**3.3V**で動作 — 5Vは非互換。カスタムピンでソフトウェアSPI（ビットバンギング）を使用します。

| ディスプレイのピン | ESP32接続 | GPIO | 備考 |
|---|---|---|---|
| **VCC** | 3.3V | — | ⚠️ 絶対に5Vを使用しない |
| **GND** | GND | — | |
| **CS** | D15 | GPIO15 | チップセレクト (Chip Select) |
| **RESET** | ENピン | — | ESP32と共有のハードウェアリセット |
| **A0 (DC)** | TX2 | GPIO17 | データ/コマンド (Data/Command) |
| **SDA (MOSI)** | D23 | GPIO23 | SPIデータ |
| **SCK** | RX2 | GPIO16 | SPIクロック |
| **LED** | 3.3V | — | 固定バックライト (空きGPIOなし) |

```
ESP32 3.3V  ────►  VCC
ESP32 GND   ────►  GND
ESP32 D15   ────►  CS
ESP32 EN    ────►  RESET
ESP32 TX2   ────►  A0 (DC)
ESP32 D23   ────►  SDA (MOSI)
ESP32 RX2   ────►  SCK
ESP32 3.3V  ────►  LED (固定バックライト)
```

> [!WARNING]
> ディスプレイの**RESET**ピンはESP32の**EN**ピンに接続してください（GPIOではありません）。これにより、ディスプレイがマイクロコントローラと一緒にリセットされます。ENがHIGH（通常動作）のとき、ディスプレイは正常に動作します。

> [!NOTE]
> ESP32 DevKit V1ブレイクアウトボードでは、**D16**および**D17**はそれぞれ**RX2**および**TX2**とラベル付けされています。端子台のラベルを使用して正しい位置を確認してください。

---

### 配線図 — ナビゲーションボタン

ディスプレイを制御する物理ボタン：短押しでページ切り替え。長押しでメニューを開く（TPA開始またはメンテナンスモード）。

| ピン | 接続 | GPIO | 設定 |
|---|---|---|---|
| **端子 1** | GPIO19 | GPIO19 | `INPUT_PULLUP` — LOWでアクティブ |
| **端子 2** | GND | — | |

```
ESP32 GPIO19 ─────── [ ボタン ] ──── GND
         INPUT_PULLUP, LOWでアクティブ (押下 = LOW)
```

> [!TIP]
> ボタンは標準的なプッシュボタンまたはタクタイルスイッチを使用してパネルに取り付けることができます。ファームウェアは**短押し**（ページ変更）と**長押し > 1秒**（メニューを開く）を検出します。

---

## 🛠️ 安全な実装上の注意点

1. **AC 接続** — 110V/220Vのすべてのハンダ付け接点および接続部は、最大限の安全性を確保するために熱収縮チューブで絶縁してください。

2. **コンデンサの極性** — すべての電解コンデンサの負極ストライプを確認してください（特に5.1Vで動作する1000µF 10V）。

3. **フライバックダイオード** — 必ずケーブル端（モーター近傍）に設置し、1.2mケーブルがアンテナのようにノイズを放射するのを防いでください。

4. **スターGND** — すべての負側基準は電源のV−端子に直接戻し、グランドループを防止してください。

5. **サイフォン現象（水力学）** — 排水ポンプ停止後に重力で水槽が排水され続けるのを防ぐため、排水ポンプと並列にソレノイドバルブを配線する（同じMOSFETチャンネルに接続し、それぞれにフライバックダイオードを取り付ける）か、ホースに空気穴を開けてください。

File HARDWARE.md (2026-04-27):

# Documentação de Arquitetura de Hardware: Sistema de Gestão de Aquário

## 📋 Visão Geral

O sistema utiliza uma topologia de **Defesa em Profundidade**, com filtragem de ruído na entrada (AC), estabilização no barramento principal (DC) e supressão de picos indutivos na borda (Atuadores).

```
┌─────────────────────┐     ┌─────────────────────┐     ┌─────────────────────┐
│  CAMADA 1: AC       │ ──► │  CAMADA 2: DC       │ ──► │  CAMADA 3: BORDA    │
│  Entrada/Proteção   │     │  Barramento/Lógica  │     │  Periféricos/Supres.│
│                     │     │                     │     │                     │
│  • Fusível AC       │     │  • Fonte 12.53V     │     │  • Diodos Flyback   │
│  • NTC (Inrush)     │     │  • LM2596 → 5.1V    │     │  • Caps desacopl.   │
│  • Filtro EMI (Y)   │     │  • Banco de Caps    │     │  • Sensores (GX12)  │
│  • Relé Canister    │     │  • MOSFET 8 canais  │     │  • Bombas + Válvula │
└─────────────────────┘     └─────────────────────┘     └─────────────────────┘
```

---

## ⚡ Camada 1: Entrada e Proteção AC (Infraestrutura)

A arquitetura da entrada de energia foca em simplicidade e máxima segurança elétrica, delegando as proteções e filtragens (como Filtro EMI e Termistor NTC/Inrush) para os circuitos profissionais já embutidos na Fonte Colmeia.

### Componentes

| Componente | Função |
|---|---|
| **Fusível de Vidro AC** (3A a 5A) | Item obrigatório: Proteção contra curto-circuito bruto e risco de incêndio |
| **Módulo Relé SSR 1CH** | Controle independente via ESP32 para o filtro Canister (AC) |

### Esquema de Ligação

```text
[ TOMADA IEC C14 ]
      │
      ├─── [ PINO TERRA (Verde) ] ────────┬─────────► [ Borne G (TERRA) da Fonte ]
      │                                   │
      │                                   └─────────► [ Pino TERRA - Tomada Canister ]
      │         
      ├─── [ PINO NEUTRO (Azul) ] ────────┬─────────► [ Borne N (NEUTRO) da Fonte ]
      │                                   │
      │                                   └─────────► [ Pino NEUTRO - Tomada Canister ]
      │
      └─── [ PINO FASE (Marrom) ] ─── [ FUSÍVEL ] ──┐
                                                    │
             ┌──────────────────────────────────────┘
             │                                  
             ├───────────────────► [ Borne L (FASE) da Fonte ]
             │
             └───► [ Parafuso 1 do Relé SSR ] ── INTERRUPTOR ──► [ Parafuso 2 do Relé SSR ] ──► [ Pino FASE - Tomada Canister ]
```

---

## 🔋 Camada 2: Barramento DC e Lógica (Distribuição)

Responsável por converter a potência para os níveis lógicos e manter a estabilidade do ESP32 durante o chaveamento das cargas pesadas.

### Componentes

| Componente | Função |
|---|---|
| **Fonte Colmeia 180W** | Ajustada para 12.53V |
| **Fusível T5AL250V** | Firewall físico para as 8 bombas e sensores |
| **LM2596** | Step-down ajustado para 5.1V (alimentação ESP32) |
| **1× 470µF 16V** | Em paralelo na entrada 12V do MOSFET (Evita queda de tensão quando as bombas ligam) |
| **4× 1000µF 10V** | Em paralelo na saída 5V (Atua como "Nobreak" para o ESP32 aguentar flutuações e picos da rede) |

### Esquema de Ligação

```text
[ FONTE 12.53V ]
   │              │
 (V+)           (V─) ──────────────────────────────┐ (GND ESTRELA)
   │              │                                │
[FUSÍVEL T5A]     │                                │
   │              │                                │
   ├──────────────┼────────────────┐               │
   │              │                │               │
[LM2596 IN+]  [LM2596 IN─]    [MOSFET VIN]   [MOSFET GND]
   │              │                │               │
(Saída 5.1V)      │         (1× 470µF 16V)         │
   │              │                │               │
(4× 1000µF 10V)   │                │               │
   │              │                │               │
[ESP32 VIN]   [ESP32 GND]          │               │
   │              │         [ 8 CANAIS MOSFET ]    │
   │              └────────────────┴───────────────┘
```

> [!IMPORTANT]
> **GND Estrela**: Todas as referências negativas devem retornar diretamente ao borne V− da fonte colmeia para evitar loops de terra.

---

## 🌊 Camada 3: Periféricos e Supressão (Borda)

Responsável por mitigar o ruído indutivo (Flyback) e estabilizar a leitura dos sensores em cabos longos (1,2m).

### Componentes

| Componente | Aplicação | Qtd |
|---|---|---|
| **Diodos FR154** (Fast Recovery) | Bombas de Recalque e Esgoto | 2 |
| **Diodos FR154** (Fast Recovery) | Bombas Peristálticas (4 Fert + 1 Prime) | 5 |
| **Diodo 1N5822** (Schottky) | Válvula Solenoide (Canal 8) | 1 |
| **Capacitores 10µF / 22µF 50V** | Desacoplamento na ponta dos sensores (GX12) | — |

> [!NOTE]
> **Total: 8 diodos flyback** — um para cada canal com motor (7× FR154 + 1× 1N5822). Todos instalados na ponta do fio, junto ao motor.

### Esquema de Ligação — Atuadores

```
[ CANAL MOSFET ] ──────────── (Fio 1.2m) ──────┬────────── (BOMBA +)
                                               │
                                         [ DIODO FLYBACK ]
                                         (Listra no POS+)
                                               │
[ GND BARRAMENTO ] ─────────── (Fio 1.2m) ─────┴────────── (BOMBA ─)
```

> [!CAUTION]
> **Diodos Flyback**: Devem ser instalados obrigatoriamente **na ponta do fio** (junto ao motor) para evitar que o cabo de 1,2m irradie ruído como uma antena.

### Esquema de Ligação — Sensor Ultrassônico (JSN-SR04T)

O sensor opera em 5V, mas o ESP32 suporta no máximo **3.3V** nos GPIOs. O pino **ECHO** precisa de um divisor de tensão resistivo para reduzir o sinal de 5V → 3.3V antes de entrar no GPIO34.

| Componente | Função |
|---|---|
| **Resistor 1kΩ** (R1) | Em série entre ECHO e GPIO34 |
| **Resistor 2kΩ** (R2) | Pull-down entre GPIO34 e GND |

**Fórmula:** `Vout = 5V × R2 / (R1 + R2) = 5 × 2k / 3k = 3.33V` ✅

```
                           ┌──────────────────┐
  ESP32 GPIO18 (TRIG) ─────┤ TRIG    JSN-SR04T│
                           │                  │
  ESP32 5V ────────────────┤ VCC              │
                           │                  │
  GND ─────────────────────┤ GND              │
                           │                  │
                           │ ECHO ────┐       │
                           └──────────┼───────┘
                                      │
                                 [ R1 = 1kΩ ]
                                      │
                    ESP32 GPIO34 ──────┤
                                      │
                                 [ R2 = 2kΩ ]
                                      │
                                    (GND)
```

> [!WARNING]
> **Nunca conecte o ECHO diretamente ao ESP32** sem o divisor de tensão. Os 5V do ECHO podem danificar permanentemente o GPIO do ESP32.

### Esquema de Ligação — Sensor Capacitivo de Nível (XKC-Y25-NPN)

Sensor sem contato que detecta a presença de líquido através da parede do vidro/tubo. Saída NPN open-collector, compatível diretamente com 3.3V do ESP32.

| Pino Sensor | Conexão |
|---|---|
| **VCC** (vermelho) | 3.3V do ESP32 |
| **GND** (preto) | GND |
| **OUT** (amarelo) | GPIO 4 (`INPUT_PULLUP`) |

```
  ESP32 3.3V ─────────── VCC (vermelho)
                                            ┌────────────────┐
  ESP32 GPIO4 ─────────── OUT (amarelo) ────┤ XKC-Y25-NPN    │
   (INPUT_PULLUP)                           │ (colado no     │
                                            │  vidro/tubo)   │
  GND ─────────────────── GND (preto)  ────┤                │
                                            └────────────────┘
```

> [!TIP]
> **Sem resistor externo necessário.** O pull-up interno do ESP32 (~45kΩ) é suficiente para o open-collector NPN. O sensor fica colado na **parte externa** do vidro do aquário no nível máximo desejado.

### Esquema de Ligação — Display TFT ST7735 (SPI)

Display colorido 1.8" 128×160 pixels. Opera em **3.3V** — incompatível com 5V. Utiliza SPI por software (bit-banging) em pinos customizados.

| Pino do Display | Conexão ESP32 | GPIO | Observação |
|---|---|---|---|
| **VCC** | 3.3V | — | ⚠️ Nunca usar 5V |
| **GND** | GND | — | |
| **CS** | D15 | GPIO15 | Chip Select |
| **RESET** | Pino EN | — | Reset hardware compartilhado com o ESP32 |
| **A0 (DC)** | TX2 | GPIO17 | Data/Command |
| **SDA (MOSI)** | D23 | GPIO23 | Dados SPI |
| **SCK** | RX2 | GPIO16 | Clock SPI |
| **LED** | 3.3V | — | Backlight fixo (sem GPIO livre disponível) |

```
ESP32 3.3V  ────►  VCC
ESP32 GND   ────►  GND
ESP32 D15   ────►  CS
ESP32 EN    ────►  RESET
ESP32 TX2   ────►  A0 (DC)
ESP32 D23   ────►  SDA (MOSI)
ESP32 RX2   ────►  SCK
ESP32 3.3V  ────►  LED (backlight fixo)
```

> [!WARNING]
> O pino **RESET** do display deve ir ao pino **EN** do ESP32 (não a um GPIO). Isso garante que o display é resetado junto com o microcontrolador. Com o pino EN em HIGH (nível normal de operação), o display funciona normalmente.

> [!NOTE]
> No breakout board ESP32 DevKit V1, os pinos **D16** e **D17** aparecem rotulados como **RX2** e **TX2** respectivamente. Use os rótulos do seu terminal para identificar a posição correta.

---

### Esquema de Ligação — Botão de Navegação

Botão físico que controla o display: pressionar brevemente muda a página; pressionar e segurar abre o menu (iniciar TPA ou modo manutenção).

| Pino | Conexão | GPIO | Configuração |
|---|---|---|---|
| **Terminal 1** | GPIO19 | GPIO19 | `INPUT_PULLUP` — ativo em LOW |
| **Terminal 2** | GND | — | |

```
ESP32 GPIO19 ─────── [ BOTÃO ] ──── GND
         INPUT_PULLUP, ativo em LOW (pressionado = LOW)
```

> [!TIP]
> O botão pode ser fixado no painel usando um push-button ou tactile switch comum. O firmware detecta **pressão curta** (troca de página) e **pressão longa > 1s** (abre menu).

---

## 🛠️ Notas de Implementação Segura

1. **Conexões AC** — Isole todas as soldas e conexões de 110V/220V com espaguete termo-retrátil para segurança máxima.

2. **Polaridade dos Capacitores** — Verificar a listra negativa em todos os eletrolíticos (especialmente os de 1000µF 10V que estão operando em 5.1V).

3. **Diodos Flyback** — Devem ser instalados obrigatoriamente na ponta do fio (junto ao motor) para evitar que o cabo de 1,2m irradie ruído como uma antena.

4. **GND Estrela** — Todas as referências negativas devem retornar diretamente ao borne V− da fonte colmeia para evitar loops de terra.

5. **Efeito Sifão (Hidráulica)** — Para evitar o esvaziamento contínuo do aquário por gravidade após o desligamento da bomba de drenagem, ligue uma válvula solenoide em paralelo com a bomba (no mesmo canal MOSFET, garantindo um diodo flyback para cada) ou faça um furo de respiro na mangueira.

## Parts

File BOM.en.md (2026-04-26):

# BOM — Bill of Materials

Complete component list for the IARA system.

---

## 🧠 Controller

| # | Component | Specification | Qty |
|---|---|---|---|
| 1 | ESP32 DevKit V1 | 38 pins, WROOM-32 | 1 |

---

## ⚡ Layer 1 — AC Input & Protection

| # | Component | Specification | Qty |
|---|---|---|---|
| 2 | IEC C14 Connector | Male panel-mount with fuse | 1 |
| 3 | AC Fuse | 3A–5A, 250V | 1 |
| 4 | NTC 5D-11 | Inrush current limiter, 5Ω cold | 1 |
| 5 | NDF 222M Capacitor | Y capacitor, Phase–Ground | 1 |
| 6 | NDF 222M Capacitor | Y capacitor, Neutral–Ground | 1 |
| 7 | SSR Relay Module 1CH | SSR, Canister filter control (AC) | 1 |

---

## 🔋 Layer 2 — DC Bus & Logic

| # | Component | Specification | Qty |
|---|---|---|---|
| 8 | 180W Switching PSU | 12V (adjusted to 12.53V) | 1 |
| 9 | T5AL250V Fuse | 5A, DC protection | 1 |
| 10 | LM2596 Module | Adjustable step-down (→ 5.1V) | 1 |
| 11 | 8-Channel MOSFET Module | IRF540N or equivalent, 12V | 1 |
| 12 | 470µF Electrolytic Cap | 16V, MOSFET input filter | 2 |
| 13 | 1000µF Electrolytic Cap | 10V, 5V output filter (ESP32) | 4 |

---

## 🌊 Layer 3 — Actuators

| # | Component | Specification | Qty |
|---|---|---|---|
| 14 | 12V Peristaltic Pump | Fertilizers (CH1–CH4) | 4 |
| 15 | 12V Peristaltic Pump | Prime / dechlorinator (CH5) | 1 |
| 16 | 12V Submersible Pump | Drain / sewage (CH6) | 1 |
| 17 | 12V Submersible Pump | Refill / top-up (CH7) | 1 |
| 18 | 12V Solenoid Valve | Normally closed (CH8) | 1 |
| 19 | Canister Filter | Controlled via AC relay | 1 |

---

## 📡 Sensors

| # | Component | Specification | Qty |
|---|---|---|---|
| 20 | JSN-SR04T | Waterproof ultrasonic, 5V | 1 |
| 21 | Capacitive Level Sensor | XKC-Y25-NPN, non-contact, 3.3–5V (GPIO 4) | 1 |
| 22 | Float Switch | Reservoir level (GPIO 35) | 1 |
| 23 | DS3231 | RTC module I2C (SDA 21 / SCL 22) | 1 |
| 24 | 1.8" TFT Display | ST7735, SPI, 128×160 | 1 |
| 24b| Push/Tactile Button | Display navigation (GPIO 0) | 1 |

---

## 🛡️ Protection & Filtering

| # | Component | Specification | Qty |
|---|---|---|---|
| 25 | FR154 Diode | Fast Recovery, pump flyback | 7 |
| 26 | 1N5822 Diode | Schottky, solenoid flyback | 1 |
| 27 | 1kΩ Resistor | ¼W, ECHO voltage divider (R1) | 1 |
| 28 | 2kΩ Resistor | ¼W, ECHO voltage divider (R2) | 1 |
| 29 | 10µF / 22µF Capacitor | 50V, sensor decoupling | 2–4 |

---

## 🔌 Connectors & Accessories

| # | Component | Specification | Qty |
|---|---|---|---|
| 30 | GX12 Aviation Connector | Panel mount, for remote sensors | 2–4 |
| 31 | Shielded Multi-core Cable | 4-5 cores, solderable to GX12, 1.2m | 2–4 |
| 32 | KRE / Wago Terminal | Power connections | ~20 |
| 33 | Heat-Shrink Tubing | NTC and solder insulation | 1m |
| 34 | 22 AWG Wire | Signal / sensors | ~5m |
| 35 | 18 AWG Wire | Power / pumps | ~10m |

---

## 📊 Component Summary

| Category | Items |
|---|---|
| Electrolytic Capacitors | 6–10 |
| Diodes (flyback) | 8 |
| Resistors | 2 |
| Motors / Pumps | 7 |
| Sensors | 4 |
| Modules (ESP32, LM2596, MOSFET, Relay, RTC, TFT) | 6 |

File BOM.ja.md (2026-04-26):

# BOM — 部品表

IARAシステムの全コンポーネントリスト。

---

## 🧠 コントローラー

| # | コンポーネント | 仕様 | 数量 |
|---|---|---|---|
| 1 | ESP32 DevKit V1 | 38ピン、WROOM-32 | 1 |

---

## ⚡ レイヤー1 — AC入力・保護

| # | コンポーネント | 仕様 | 数量 |
|---|---|---|---|
| 2 | IEC C14コネクタ | パネルマウント（ヒューズ付） | 1 |
| 3 | ACヒューズ | 3A–5A、250V | 1 |
| 4 | NTC 5D-11 | 突入電流制限器、5Ω（冷時） | 1 |
| 5 | NDF 222Mコンデンサ | Yコンデンサ、相–接地 | 1 |
| 6 | NDF 222Mコンデンサ | Yコンデンサ、中性–接地 | 1 |
| 7 | SSRリレーモジュール 1CH | SSR、キャニスターフィルター制御（AC） | 1 |

---

## 🔋 レイヤー2 — DCバス・ロジック

| # | コンポーネント | 仕様 | 数量 |
|---|---|---|---|
| 8 | スイッチング電源 180W | 12V（12.53Vに調整） | 1 |
| 9 | ヒューズ T5AL250V | 5A、DC保護 | 1 |
| 10 | LM2596モジュール | 可変ステップダウン（→ 5.1V） | 1 |
| 11 | 8チャンネルMOSFETモジュール | IRF540N相当、12V | 1 |
| 12 | 電解コンデンサ 470µF | 16V、MOSFET入力フィルタ | 2 |
| 13 | 電解コンデンサ 1000µF | 10V、5V出力フィルタ（ESP32） | 4 |

---

## 🌊 レイヤー3 — アクチュエーター

| # | コンポーネント | 仕様 | 数量 |
|---|---|---|---|
| 14 | 12Vペリスタルティックポンプ | 肥料（CH1–CH4） | 4 |
| 15 | 12Vペリスタルティックポンプ | プライム/脱塩素剤（CH5） | 1 |
| 16 | 12V水中ポンプ | 排水用（CH6） | 1 |
| 17 | 12V水中ポンプ | 給水用（CH7） | 1 |
| 18 | 12Vソレノイドバルブ | 常閉型（CH8） | 1 |
| 19 | キャニスターフィルター | ACリレー制御 | 1 |

---

## 📡 センサー

| # | コンポーネント | 仕様 | 数量 |
|---|---|---|---|
| 20 | JSN-SR04T | 防水超音波センサー、5V | 1 |
| 21 | 静電容量式水位センサー | XKC-Y25-NPN、非接触、3.3–5V（GPIO 4） | 1 |
| 22 | フロートスイッチ | リザーバー水位（GPIO 35） | 1 |
| 23 | DS3231 | RTCモジュール I2C（SDA 21 / SCL 22） | 1 |
| 24 | TFTディスプレイ 1.8" | ST7735、SPI、128×160 | 1 |
| 24b| プッシュ/タクタイルボタン | ディスプレイナビゲーション (GPIO 0) | 1 |

---

## 🛡️ 保護・フィルタリング

| # | コンポーネント | 仕様 | 数量 |
|---|---|---|---|
| 25 | FR154ダイオード | 高速リカバリ、ポンプフライバック | 7 |
| 26 | 1N5822ダイオード | ショットキー、ソレノイドフライバック | 1 |
| 27 | 1kΩ抵抗 | ¼W、ECHO分圧回路（R1） | 1 |
| 28 | 2kΩ抵抗 | ¼W、ECHO分圧回路（R2） | 1 |
| 29 | 10µF / 22µFコンデンサ | 50V、センサーデカップリング | 2–4 |

---

## 🔌 コネクタ・アクセサリ

| # | コンポーネント | 仕様 | 数量 |
|---|---|---|---|
| 30 | GX12航空コネクタ | パネルマウント、リモートセンサー用 | 2–4 |
| 31 | シールド付き多芯ケーブル | 4〜5コア、GX12用はんだ付け可、1.2m | 2–4 |
| 32 | KRE / Wagoターミナル | 電力接続 | 約20 |
| 33 | 熱収縮チューブ | NTCおよびハンダの絶縁 | 1m |
| 34 | 22 AWGワイヤ | 信号/センサー | 約5m |
| 35 | 18 AWGワイヤ | 電力/ポンプ | 約10m |

---

## 📊 数量サマリー

| カテゴリ | 数量 |
|---|---|
| 電解コンデンサ | 6–10 |
| ダイオード（フライバック） | 8 |
| 抵抗 | 2 |
| モーター/ポンプ | 7 |
| センサー | 4 |
| モジュール（ESP32、LM2596、MOSFET、リレー、RTC、TFT） | 6 |

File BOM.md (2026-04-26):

# BOM — Bill of Materials

Lista completa de componentes do sistema IARA.

---

## 🧠 Controlador

| # | Componente | Especificação | Qtd |
|---|---|---|---|
| 1 | ESP32 DevKit V1 | 38 pinos, WROOM-32 | 1 |

---

## ⚡ Camada 1 — Entrada AC e Proteção

| # | Componente | Especificação | Qtd |
|---|---|---|---|
| 2 | Conector IEC C14 | Macho painel com fusível | 1 |
| 3 | Fusível AC | 3A–5A, 250V | 1 |
| 4 | NTC 5D-11 | Limitador inrush, 5Ω a frio | 1 |
| 5 | Capacitor NDF 222M | Capacitor Y, Fase–Terra | 1 |
| 6 | Capacitor NDF 222M | Capacitor Y, Neutro–Terra | 1 |
| 7 | Módulo Relé SSR 1CH | SSR, controle do Canister (AC) | 1 |

---

## 🔋 Camada 2 — Barramento DC e Lógica

| # | Componente | Especificação | Qtd |
|---|---|---|---|
| 8 | Fonte Colmeia 180W | 12V (ajustada 12.53V) | 1 |
| 9 | Fusível T5AL250V | 5A, proteção DC | 1 |
| 10 | Módulo LM2596 | Step-down ajustável (→ 5.1V) | 1 |
| 11 | Módulo MOSFET 8 canais | IRF540N ou equivalente, 12V | 1 |
| 12 | Capacitor eletrolítico 470µF | 16V, filtro entrada MOSFET | 2 |
| 13 | Capacitor eletrolítico 1000µF | 10V, filtro saída 5V (ESP32) | 4 |

---

## 🌊 Camada 3 — Atuadores

| # | Componente | Especificação | Qtd |
|---|---|---|---|
| 14 | Bomba peristáltica 12V | Fertilizantes (CH1–CH4) | 4 |
| 15 | Bomba peristáltica 12V | Prime / desclorificante (CH5) | 1 |
| 16 | Bomba submersível 12V | Esgoto / drenagem (CH6) | 1 |
| 17 | Bomba submersível 12V | Recalque / refill (CH7) | 1 |
| 18 | Válvula solenoide 12V | Normalmente fechada (CH8) | 1 |
| 19 | Filtro canister | Controlado via relé AC | 1 |

---

## 📡 Sensores

| # | Componente | Especificação | Qtd |
|---|---|---|---|
| 20 | JSN-SR04T | Ultrassônico à prova d'água, 5V | 1 |
| 21 | Sensor capacitivo de nível | XKC-Y25-NPN, sem contato, 3.3–5V (GPIO 4) | 1 |
| 22 | Boia float switch | Nível do reservatório (GPIO 35) | 1 |
| 23 | DS3231 | Módulo RTC I2C (SDA 21 / SCL 22) | 1 |
| 24 | Display TFT 1.8" | ST7735, SPI, 128×160 | 1 |
| 24b| Botão Push/Tactile | Navegação do display (GPIO 0) | 1 |

---

## 🛡️ Proteção e Filtragem

| # | Componente | Especificação | Qtd |
|---|---|---|---|
| 25 | Diodo FR154 | Fast Recovery, flyback bombas | 7 |
| 26 | Diodo 1N5822 | Schottky, flyback solenoide | 1 |
| 27 | Resistor 1kΩ | ¼W, divisor tensão ECHO (R1) | 1 |
| 28 | Resistor 2kΩ | ¼W, divisor tensão ECHO (R2) | 1 |
| 29 | Capacitor 10µF / 22µF | 50V, desacoplamento sensores | 2–4 |

---

## 🔌 Conectores e Acessórios

| # | Componente | Especificação | Qtd |
|---|---|---|---|
| 30 | Conector GX12 (Aviação) | Painel fêmea/macho, para sensores | 2–4 |
| 31 | Cabo blindado multi-vias | 4 a 5 vias, soldável no GX12, 1.2m | 2–4 |
| 32 | Borne KRE / Wago | Conexões de potência | ~20 |
| 33 | Espaguete termo-retrátil | Isolamento NTC e soldas | 1m |
| 34 | Fio 22 AWG | Sinal / sensores | ~5m |
| 35 | Fio 18 AWG | Potência / bombas | ~10m |

---

## 📊 Resumo de Quantidades

| Categoria | Itens |
|---|---|
| Capacitores eletrolíticos | 6–10 |
| Diodos (flyback) | 8 |
| Resistores | 2 |
| Motores / bombas | 7 |
| Sensores | 4 |
| Módulos (ESP32, LM2596, MOSFET, Relé, RTC, TFT) | 6 |

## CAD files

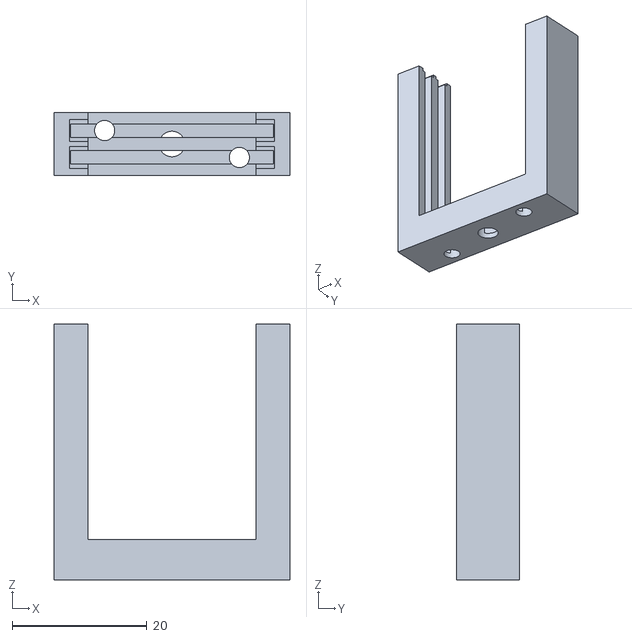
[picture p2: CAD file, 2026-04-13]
3d_models/electrodes_support.stl
35.0 x 9.40 x 38.0

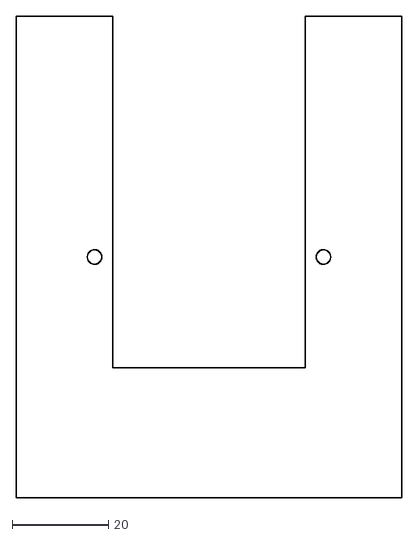
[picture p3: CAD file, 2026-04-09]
pump_shelf_test.dxf
80.0 x 100.0

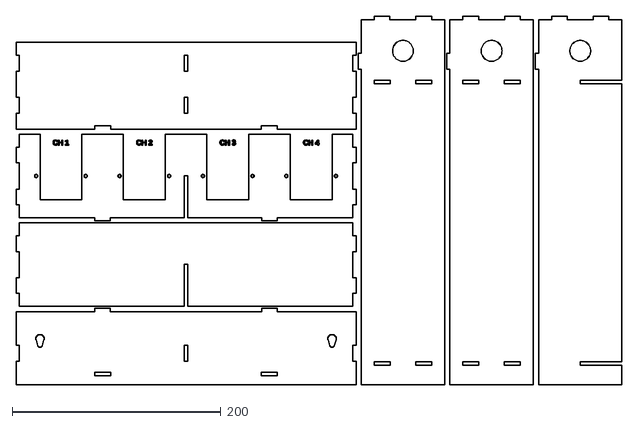
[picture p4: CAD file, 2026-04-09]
3d_models/dosing_pump_support_laser.dxf
581.0 x 353.0

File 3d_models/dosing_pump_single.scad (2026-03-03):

// ============================================================
// IARA - Suporte Individual para 1 Bomba Dosadora (Prime)
// Arquivo: dosing_pump_single.scad
// Descrição: Suporte para 1 bomba + 1 garrafa Seachem 500ml
//            Layout vertical: bomba em cima, garrafa embaixo
//            Montagem na parede
// ============================================================

$fn = 60;

// ============================================================
// PARÂMETROS
// ============================================================

// -- Garrafa Seachem 500ml (dimensões reais) --
bottle_diameter = 67; // mm (65mm real + 2mm folga)
bottle_height = 185; // mm (18.5cm)
bottle_holder_h = 45; // mm - altura do anel
bottle_wall = 2.5; // mm

// -- Bomba dosadora peristáltica (dimensões reais) --
pump_base_d = 54; // mm (diâmetro da base)
pump_body_d = 48; // mm (diâmetro do corpo)
pump_height = 46.3; // mm (altura total)
pump_mount_holes = 50; // mm (distância entre furos)
pump_mount_hole_d = 4; // mm (Ø furos)
pump_clearance = 2; // mm

// -- Estrutura --
wall = 3; // mm
base_t = 4; // mm - espessura da base
bracket_outer_d = pump_base_d + pump_clearance * 2 + wall * 2;

// -- Backplate (placa traseira para parede) --
bp_width = bracket_outer_d + 20; // mm
bp_height = pump_height + 20; // mm
bp_thickness = 4; // mm
mount_hole_d = 5; // mm
mount_slot_l = 8; // mm

// -- Conector P4 --
p4_hole_d = 8; // mm

// -- Prateleira da garrafa --
shelf_width = bottle_diameter + bottle_wall * 2 + 16;
shelf_depth = bottle_diameter + bottle_wall * 2 + 10;

// ============================================================
// MÓDULOS
// ============================================================

// --- Bracket circular da bomba ---
module pump_bracket() {
  cradle_h = pump_height * 0.6;

  difference() {
    union() {
      // Base circular
      cylinder(d=bracket_outer_d, h=base_t);

      // Berço cilíndrico
      difference() {
        cylinder(d=bracket_outer_d, h=cradle_h);
        translate([0, 0, base_t])
          cylinder(d=pump_base_d + pump_clearance * 2, h=cradle_h + 1);
      }

      // Clips de retenção (3 a 120°)
      for (a = [60, 180, 300]) {
        rotate([0, 0, a])
          translate([pump_body_d / 2 + pump_clearance, 0, cradle_h - 6]) {
            difference() {
              cylinder(d=7, h=6);
              translate([-5, -3.5, 4])
                cube([5, 7, 3]);
            }
          }
      }
    }

    // Furos de montagem (2 orelhas)
    for (dx = [-pump_mount_holes / 2, pump_mount_holes / 2])
      translate([dx, 0, -0.1])
        cylinder(d=pump_mount_hole_d, h=base_t + 0.2);

    // Abertura frontal para mangueiras
    translate([-pump_body_d / 3, -bracket_outer_d / 2 - 1, base_t])
      cube([pump_body_d * 2 / 3, bracket_outer_d / 3, cradle_h]);

    // Abertura traseira para fios
    translate([-10, bracket_outer_d / 4, base_t + 5])
      cube([20, bracket_outer_d / 2, 15]);
  }
}

// --- Backplate (placa de montagem na parede) ---
module backplate() {
  difference() {
    union() {
      // Placa traseira com cantos arredondados
      hull() {
        for (x = [-bp_width / 2 + 4, bp_width / 2 - 4])
          for (z = [4, bp_height - 4])
            translate([x, 0, z])
              rotate([-90, 0, 0])
                cylinder(r=4, h=bp_thickness);
      }

      // Base para a bomba (projeção frontal)
      translate([0, bp_thickness, bp_height / 2])
        rotate([-90, 0, 0])
          cylinder(d=bracket_outer_d + 4, h=base_t);
    }

    // Furos de montagem na parede (slots)
    for (x = [-bp_width / 2 + 10, bp_width / 2 - 10]) {
      for (z = [12, bp_height - 12]) {
        translate([x, -0.1, z])
          rotate([-90, 0, 0])
            hull() {
              cylinder(d=mount_hole_d, h=bp_thickness + 0.2);
              translate([mount_slot_l, 0, 0])
                cylinder(d=mount_hole_d, h=bp_thickness + 0.2);
            }
      }
    }

    // Furo para cabo P4
    translate([bp_width / 2 - 15, -0.1, bp_height / 2])
      rotate([-90, 0, 0])
        cylinder(d=p4_hole_d, h=bp_thickness + 0.2);

    // Furos para mangueiras
    translate([-10, -0.1, bp_height / 2 - 15])
      rotate([-90, 0, 0])
        cylinder(d=6, h=bp_thickness + 0.2);
    translate([10, -0.1, bp_height / 2 - 15])
      rotate([-90, 0, 0])
        cylinder(d=6, h=bp_thickness + 0.2);
  }

  // Etiqueta "PRIME"
  translate([0, -0.1, bp_height - 8])
    rotate([90, 0, 0])
      linear_extrude(0.6)
        text(
          "PRIME", size=6, halign="center", valign="center",
          font="Liberation Sans:style=Bold"
        );
}

// --- Holder da garrafa ---
module bottle_holder_single() {
  difference() {
    union() {
      // Base com cantos arredondados
      hull() {
        for (x = [-shelf_width / 2 + 4, shelf_width / 2 - 4])
          for (y = [-shelf_depth / 2 + 4, shelf_depth / 2 - 4])
            translate([x, y, 0])
              cylinder(r=4, h=base_t);
      }

      // Paredes laterais
      difference() {
        hull() {
          for (x = [-shelf_width / 2 + 4, shelf_width / 2 - 4])
            for (y = [-shelf_depth / 2 + 4, shelf_depth / 2 - 4])
              translate([x, y, 0])
                cylinder(r=4, h=bottle_holder_h);
        }
        translate([0, 0, base_t])
          hull() {
            for (x = [-shelf_width / 2 + wall + 4, shelf_width / 2 - wall - 4])
              for (y = [-shelf_depth / 2 + wall + 4, shelf_depth / 2 - wall - 4])
                translate([x, y, 0])
                  cylinder(r=4, h=bottle_holder_h + 1);
          }
      }

      // Anel interno para a garrafa
      difference() {
        cylinder(d=bottle_diameter + bottle_wall * 2, h=bottle_holder_h);
        translate([0, 0, base_t])
          cylinder(d=bottle_diameter, h=bottle_holder_h);
      }

      // Abas de retenção (3 pontos)
      for (a = [0, 120, 240]) {
        rotate([0, 0, a])
          translate([bottle_diameter / 2 - 1, 0, bottle_holder_h - 4])
            difference() {
              cylinder(d=5, h=4);
              translate([0, 0, -0.1])
                cylinder(d=bottle_diameter - 2, h=4.2);
            }
      }
    }

    // Dreno no fundo
    translate([0, 0, -0.1])
      cylinder(d=18, h=base_t + 0.2);

    // Fenda frontal para encaixe/retirada
    translate([-bottle_diameter / 4, -shelf_depth / 2 - 1, base_t + 12])
      cube([bottle_diameter / 2, wall + 2, bottle_holder_h]);

    // Furos de montagem na parede (traseiro)
    for (x = [-shelf_width / 2 + 8, shelf_width / 2 - 8]) {
      translate([x, shelf_depth / 2 - 0.1, bottle_holder_h / 2])
        rotate([-90, 0, 0])
          hull() {
            cylinder(d=mount_hole_d, h=wall + 0.2);
            translate([mount_slot_l, 0, 0])
              cylinder(d=mount_hole_d, h=wall + 0.2);
          }
    }
  }

  // Etiqueta "PRIME"
  translate([0, -shelf_depth / 2 - 0.1, bottle_holder_h / 2])
    rotate([90, 0, 0])
      linear_extrude(0.6)
        text(
          "PRIME", size=5, halign="center", valign="center",
          font="Liberation Sans:style=Bold"
        );
}

// ============================================================
// MONTAGEM COMPLETA
// ============================================================

module full_single_pump() {
  // Backplate com bracket (montado na parede)
  color("SteelBlue", 0.9) {
    backplate();

    // Bracket da bomba na backplate
    translate([0, bp_thickness + base_t, bp_height / 2])
      rotate([-90, 0, 0])
        pump_bracket();
  }

  // Prateleira da garrafa (abaixo)
  gap = 25; // espaço para mangueiras
  color("SteelBlue", 0.8)
    translate([0, bp_thickness / 2 + shelf_depth / 2 - 5, -gap - bottle_holder_h])
      bottle_holder_single();

  // Ghost da garrafa
  %translate([0, bp_thickness / 2 + shelf_depth / 2 - 5, -gap - bottle_holder_h + base_t])
    color("ForestGreen", 0.2)
      cylinder(d=bottle_diameter - 2, h=bottle_height);

  // Ghost da bomba
  %translate([0, bp_thickness + base_t, bp_height / 2])
    rotate([-90, 0, 0])
      color("DimGray", 0.3)
        cylinder(d=pump_body_d, h=pump_height);
}

// --- Renderizar ---
full_single_pump();

// ============================================================
// VARIANTES PARA IMPRESSÃO
// ============================================================

// --- Apenas backplate + bracket ---
// backplate();
// translate([0, bp_thickness + base_t, bp_height/2])
//     rotate([-90,0,0]) pump_bracket();

// --- Apenas holder da garrafa ---
// bottle_holder_single();
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

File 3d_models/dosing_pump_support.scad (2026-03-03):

// ============================================================
// IARA - Suporte para 4 Bombas Dosadoras + 4 Garrafas Seachem 500ml
// Arquivo: dosing_pump_support.scad
// Descrição: Layout vertical - bombas em cima, garrafas embaixo
//            Montagem na parede, com fiação e tampa de acrílico
// ============================================================

// ---- Resolução de renderização ----
$fn = 60; // Aumentar para 120+ na exportação final STL

// ============================================================
// PARÂMETROS AJUSTÁVEIS
// ============================================================

// -- Garrafa Seachem 500ml (dimensões reais) --
bottle_diameter = 67; // mm (65mm real + 2mm folga)
bottle_height = 185; // mm (18.5cm)
bottle_holder_h = 40; // mm - altura do anel de retenção
bottle_wall = 2.5; // mm - espessura da parede do holder

// -- Bomba dosadora peristáltica (dimensões reais) --
pump_base_d = 54; // mm (diâmetro da base / orelhas)
pump_body_d = 48; // mm (diâmetro do corpo principal)
pump_motor_d = 31.8; // mm (diâmetro do motor no topo)
pump_height = 46.3; // mm (altura total)
pump_mount_holes = 50; // mm (distância entre furos das orelhas)
pump_mount_hole_d = 4; // mm (diâmetro dos furos de montagem)
pump_clearance = 2; // mm (folga ao redor da bomba)

// -- Layout geral --
num_stations = 4; // Número de estações
station_spacing = 85; // mm - espaçamento entre centros
wall_thickness = 3; // mm - espessura das paredes
base_thickness = 4; // mm - espessura da base/fundo

// -- Prateleira superior (bombas + fiação) --
shelf_depth = 80; // mm - profundidade da prateleira
shelf_height = 55; // mm - altura (bomba + espaço fiação)

// -- Fiação elétrica (atrás das bombas na prateleira) --
wiring_zone_d = 25; // mm - profundidade da zona de fiação
cable_entry_d = 10; // mm - diâmetro furo entrada de cabos
terminal_block_w = 12; // mm - largura de um borne

// -- Tampa de acrílico (prateleira superior) --
acrylic_thickness = 3; // mm
lid_screw_d = 3.2; // mm - M3
lid_post_d = 7; // mm - diâmetro dos postes

// -- Montagem na parede --
mount_hole_d = 5; // mm
mount_slot_length = 8; // mm

// ============================================================
// DIMENSÕES CALCULADAS
// ============================================================

total_width = (num_stations - 1) * station_spacing + pump_base_d + pump_clearance * 2 + wall_thickness * 2 + 10;
shelf_inner_d = shelf_depth - wall_thickness * 2;

// ============================================================
// MÓDULOS UTILITÁRIOS
// ============================================================

module rounded_rect(w, d, h, r = 5) {
  hull() {
    for (x = [-w / 2 + r, w / 2 - r])
      for (y = [-d / 2 + r, d / 2 - r])
        translate([x, y, 0])
          cylinder(r=r, h=h);
  }
}

// ============================================================
// PRATELEIRA SUPERIOR (bombas + fiação)
// ============================================================

module pump_shelf() {
  difference() {
    union() {
      // Caixa da prateleira (bandeja com fundo e paredes)
      difference() {
        rounded_rect(total_width, shelf_depth, shelf_height, 4);
        translate([0, 0, base_thickness])
          rounded_rect(
            total_width - wall_thickness * 2,
            shelf_depth - wall_thickness * 2,
            shelf_height, 3
          );
      }
      // Fundo sólido
      rounded_rect(total_width, shelf_depth, base_thickness, 4);

      // Divisória entre zona de bombas (frente) e fiação (trás)
      translate(
        [
          -total_width / 2 + wall_thickness + 1,
          -shelf_depth / 2 + shelf_depth - wiring_zone_d - wall_thickness,
          base_thickness,
        ]
      )
        cube([total_width - wall_thickness * 2 - 2, wall_thickness, shelf_height * 0.7]);
    }

    // Furos para mangueiras passarem pelo fundo (para as garrafas embaixo)
    for (i = [0:num_stations - 1]) {
      x = -( (num_stations - 1) * station_spacing) / 2 + i * station_spacing;
      // Furo da mangueira de sucção (garrafa → bomba)
      translate([x - 10, -shelf_depth / 2 + shelf_depth / 2 - wiring_zone_d / 2 - 5, -0.1])
        cylinder(d=8, h=base_thickness + 0.2);
      // Furo da mangueira de saída (bomba → aquário)
      translate([x + 10, -shelf_depth / 2 + shelf_depth / 2 - wiring_zone_d / 2 - 5, -0.1])
        cylinder(d=8, h=base_thickness + 0.2);
    }

    // Passagens de fios na divisória (um por bomba)
    for (i = [0:num_stations - 1]) {
      x = -( (num_stations - 1) * station_spacing) / 2 + i * station_spacing;
      divider_y = -shelf_depth / 2 + shelf_depth - wiring_zone_d - wall_thickness;
      translate([x - 8, divider_y - 0.1, base_thickness + 5])
        cube([16, wall_thickness + 0.2, 12]);
    }

    // Furos de entrada de cabos (painel traseiro - vindos da caixa eletrônica)
    for (x_off = [-total_width / 4, total_width / 4]) {
      translate([x_off, shelf_depth / 2 - 0.1, shelf_height / 2 + 5])
        rotate([90, 0, 0])
          rotate([0, 0, 0])
            cylinder(d=cable_entry_d, h=wall_thickness + 0.2);
    }

    // Ventilação lateral
    for (side = [-1, 1]) {
      translate(
        [
          side * (total_width / 2 - wall_thickness - 0.1),
          shelf_depth / 2 - wiring_zone_d - 5,
          base_thickness + 8,
        ]
      )
        cube([wall_thickness + 0.2, wiring_zone_d - 5, 20]);
    }
  }
}

// --- Suporte individual da bomba (circular, dentro da prateleira) ---
module pump_bracket() {
  bracket_outer_d = pump_base_d + pump_clearance * 2 + wall_thickness * 2;
  cradle_h = pump_height * 0.6;

  difference() {
    union() {
      // Base circular
      cylinder(d=bracket_outer_d, h=base_thickness);

      // Berço cilíndrico
      difference() {
        cylinder(d=bracket_outer_d, h=cradle_h);
        translate([0, 0, base_thickness])
          cylinder(d=pump_base_d + pump_clearance * 2, h=cradle_h + 1);
      }

      // Clips de retenção (3 a 120°)
      for (a = [60, 180, 300]) {
        rotate([0, 0, a])
          translate([pump_body_d / 2 + pump_clearance, 0, cradle_h - 6]) {
            difference() {
              cylinder(d=7, h=6);
              translate([-5, -3.5, 4])
                cube([5, 7, 3]);
            }
          }
      }
    }

    // Furos de montagem (2 orelhas opostas)
    for (dx = [-pump_mount_holes / 2, pump_mount_holes / 2])
      translate([dx, 0, -0.1])
        cylinder(d=pump_mount_hole_d, h=base_thickness + 0.2);

    // Abertura frontal para mangueiras
    translate([-pump_body_d / 3, -bracket_outer_d / 2 - 1, base_thickness])
      cube([pump_body_d * 2 / 3, bracket_outer_d / 3, cradle_h]);

    // Abertura traseira para fios
    translate([-10, bracket_outer_d / 4, base_thickness + 5])
      cube([20, bracket_outer_d / 2, 15]);
  }
}

// --- Postes para bornes na zona de fiação ---
module wiring_mounts() {
  for (i = [0:num_stations - 1]) {
    x = -( (num_stations - 1) * station_spacing) / 2 + i * station_spacing;
    wiring_y = shelf_depth / 2 - wiring_zone_d / 2;

    // Posts para borne
    for (dx = [-terminal_block_w / 2 - 1, terminal_block_w / 2 + 1]) {
      translate([x + dx, wiring_y, base_thickness]) {
        difference() {
          cylinder(d=5, h=8);
          translate([0, 0, 3])
            cylinder(d=2.5, h=5.1);
        }
      }
    }

    // Etiqueta M1-M4
    translate([x, wiring_y + 12, base_thickness])
      linear_extrude(0.6)
        text(
          str("M", i + 1), size=5, halign="center", valign="center",
          font="Liberation Sans:style=Bold"
        );
  }
}

// --- Etiquetas CH1-CH4 na frente da prateleira ---
module pump_labels() {
  for (i = [0:num_stations - 1]) {
    x = -( (num_stations - 1) * station_spacing) / 2 + i * station_spacing;
    translate([x, -shelf_depth / 2 - 0.1, shelf_height / 2])
      rotate([90, 0, 0])
        linear_extrude(0.6)
          text(
            str("CH", i + 1), size=6, halign="center", valign="center",
            font="Liberation Sans:style=Bold"
          );
  }
}

// ============================================================
// PRATELEIRA INFERIOR (garrafas)
// ============================================================

// Distância vertical entre prateleira e porta-garrafas
shelf_to_bottles = 20; // mm - espaço para mangueiras

module bottle_shelf() {
  shelf_w = total_width;
  shelf_d = bottle_diameter + bottle_wall * 2 + 10;

  difference() {
    union() {
      // Base da prateleira de garrafas
      rounded_rect(shelf_w, shelf_d, base_thickness, 4);

      // Paredes laterais baixas (guarda)
      difference() {
        rounded_rect(shelf_w, shelf_d, bottle_holder_h, 4);
        translate([0, 0, base_thickness])
          rounded_rect(
            shelf_w - wall_thickness * 2,
            shelf_d - wall_thickness * 2,
            bottle_holder_h + 1, 3
          );
      }
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

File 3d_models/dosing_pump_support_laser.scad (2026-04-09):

// ============================================================
// IARA - Suporte para 4 Bombas Dosadoras + Garrafas Seachem 500ml
// Versão: Corte a Laser (Acrílico ou MDF 3mm)
// ============================================================

$fn = 60;

// -- Parâmetros de Material e Tolerância --
mat_t = 3;       // mm - Espessura do material
tol = 0.15;      // mm - Folga para encaixes (aumentar furos por tol*2 para encaixe macio)

// -- Dimensões Gerais do Rack --
num_stations = 4;
station_spacing = 80;
rack_w = 320;    // Largura interna clara
rack_h = 350;    // Altura total
depth = 80;      // Profundidade (frente a trás) - Otimizado para caber tudo

// -- Posições Z das Prateleiras --
bot_z = 20;      // Base inferior (apoio de garrafas)
col_z = 80;      // Anel (colar) de retenção das garrafas
pmp_z = 290;     // Prateleira das bombas (Deixa 203mm de vão livre para garrafas de 185)

// -- Dimensões dos Componentes --
bottle_d = 64;   // Diâmetro real da garrafa Seachem 500ml
bottle_hole_d = 65; // Furo final exato de 65mm para abraçar a garrafa

pump_body_d = 48;
pump_holes = 47.5;         // Entre eixos de fixação
pump_mount_hole_d = 3;     // Diâmetro do parafuso
hose_hole_d = 8;
hose_slot_back = 23;       // Quanto o vão de mangueira avança para a traseira (atrás dos furos)
tab_w = 15;      // Largura padrão das abas (tabs) de fixação

// ============================================================
// MÓDULOS DE COMPONENTES 2D (Para Corte Laser)
// ============================================================

// --- Centralizar furos de fixação (Keyhole) ---
module keyhole() {
    hull() {
        translate([0, 4]) circle(d=8);    // Passagem da cabeça do parafuso
        translate([0, -2]) circle(d=4.5); // Descanso do corpo do parafuso
    }
}

// Fica posicionado em Y=0. Cobre apenas a parte de trás das bombas (z = 280 a rack_h).
module back_panel_2d() {
    union() {
        difference() {
            // Corpo Principal: z de 280 a rack_h
            translate([-rack_w/2 - mat_t, 280]) 
                square([rack_w + 2*mat_t, rack_h - 280]);
            
            // Furos de fixação na parede (Keyholes)
            for (x = [-140, 140]) {
                translate([x, 320]) keyhole();
            }
            
            // Slots Verticais: para Painéis Laterais (x = -161.5, +161.5)
            for (x = [-rack_w/2 - mat_t/2, rack_w/2 + mat_t/2]) {
                for (z = [310]) {
                    translate([x, z]) 
                        square([mat_t + tol*2, tab_w + tol*2], center=true);
                }
            }
            
            // Slots Verticais: para Painel Divisório Central (x = 0)
            for (z = [310]) {
                translate([0, z]) 
                    square([mat_t + tol*2, tab_w + tol*2], center=true);
            }
            
            // Slots Horizontais: para as abas da Prateleira das Bombas
            for (z = [pmp_z]) {
                for (x = [-80, 80]) {
                    translate([x, z]) 
                        square([tab_w + tol*2, mat_t + tol*2], center=true);
                }
            }
        }
        
        // Tabs Superiores: para a Tampa (Top Lid)
        for (x = [-80, 80]) {
            translate([x - tab_w/2, rack_h])
                square([tab_w, mat_t]);
        }
    }
    
    // Gravação Logo
    color("red")
    translate([0, rack_h - 25])
        text("I A R A", size=10, halign="center", valign="center", font="Liberation Sans:style=Bold");
}

// ============================================================
// 2. PAINÉIS VERTICAIS (Laterais e Central)
// ============================================================
// Ficam posicionados no eixo YZ da montagem. 
// A profundidade está no eixo X (0 a depth), a altura está no Y (0 a rack_h).
module vertical_panel_2d(is_mid=false) {
    union() {
        difference() {
            // Corpo Principal
            square([depth, rack_h]);
            
            // Tratamento das interações com Prateleiras:
            if (is_mid) {
                // Painel Central (Divisória) usa 'Halving Joints'
                for (z = [bot_z, pmp_z]) { // <-- Removido col_z para economizar placa
                    // Recorte partindo do centro até a frente (depth/2 até depth)
                    translate([depth/2, z - mat_t/2 - tol]) 
                        square([depth/2 + 1, mat_t + tol*2]);
                }
            } else {
                // Painéis Laterais (Esquerdo/Direito) usam slots normais
                for (z = [bot_z, pmp_z]) {
                    for (x = [20, 60]) { // Movido levemente pra caber no depth=80
                        translate([x - tab_w/2 - tol, z - mat_t/2 - tol]) 
                            square([tab_w + tol*2, mat_t + tol*2]);
                    }
                }
            }
            
            // Furo central de 20mm para condução Mestre dos Fios/Cabos
            // Fica localizado na "caixa elétrica" que se forma entre a placa de bombas e a tampa
            translate([depth/2, rack_h - 30]) circle(d=20);
        }
        
        // Tabs Traseiros: saem do zero para a esquerda e encaixam no Painel Traseiro (agora apenas na área superior)
        for (z = [310]) {
            translate([-mat_t, z - tab_w/2])
                square([mat_t, tab_w]);
        }
        
        // Tabs Superiores: para a Tampa (Top Lid)
        for (x = [20, 60]) { 
            translate([x - tab_w/2, rack_h])
                square([tab_w, mat_t]);
        }
    }
}

// ============================================================
// 3. PRATELEIRAS (Base genérica e específicas)
// ============================================================
// Posicionadas no eixo XY da montagem. X é a largura, Y é a profundidade.
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

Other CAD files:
3d_models/electrodes_support.scad
3d_models/electronics_enclosure.scad
3d_models/electronics_enclosure_3d.scad
3d_models/electronics_enclosure_laser.scad
3d_models/pump_shelf_test.scad

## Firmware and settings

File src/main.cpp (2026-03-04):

// =============================================================================
// AQUARIUM AUTOMATION FIRMWARE - ESP32
// =============================================================================
// TPA (Troca Parcial de Água), Fertilization & Filtration Controller
// Priority: Flood prevention and temporal precision
//
// Architecture: OOP with 5 manager classes
//   - SafetyWatchdog: sensor reads, overflow detection, emergency actions
//   - TimeManager:    RTC DS3231 + NTP synchronization
//   - WaterManager:   TPA state machine (6 states)
//   - FertManager:    Daily dosing with NVS deduplication
//   - WebManager:     Embedded web dashboard + Serial command interface
// =============================================================================

#include "Config.h"
#include "DisplayManager.h"
#include "FertManager.h"
#include "NotifyManager.h"
#include "SafetyWatchdog.h"
#include "TimeManager.h"
#include "WaterManager.h"
#include "WebManager.h"
#include <Arduino.h>
#include <LittleFS.h>
#include <esp_task_wdt.h>
#include <esp_wifi.h>

// ---- Global instances ----
SafetyWatchdog safety;
TimeManager timeMgr;
WaterManager waterMgr;
FertManager fertMgr;
WebManager webMgr;
DisplayManager displayMgr;
NotifyManager notifyMgr;

// ---- Scheduling state ----
bool fertDoneThisMinute = false; // Prevent re-triggering within same minute
uint8_t lastFertMinute = 255;
bool tpaDoneThisMinute = false;
uint8_t lastTPAMinute = 255;
bool emergencyNotified = false;   // Prevent repeated emergency notifications
bool tpaCompleteNotified = false; // Prevent repeated TPA complete notifications
bool tpaErrorNotified = false;    // Prevent repeated TPA error notifications

// ---- WiFi Retry State ----
unsigned long lastWiFiRetryTime = 0;
const unsigned long WIFI_RETRY_INTERVAL_MS = 30000; // 30 seconds

// =============================================================================
// SETUP
// =============================================================================
void setup() {
  // --- Step 1: Initialize all output pins LOW FIRST (safety critical) ---
  for (uint8_t i = 0; i < NUM_OUTPUT_PINS; i++) {
    pinMode(OUTPUT_PINS[i], OUTPUT);
    digitalWrite(OUTPUT_PINS[i], LOW);
  }

  // --- Step 2: Serial ---
  Serial.begin(115200);
  delay(2000);
  Serial.println("\n==========================================");
  Serial.println("  AQUARIUM AUTOMATION - ESP32 Firmware");
  Serial.println("  v3.0.0 - Web Dashboard");
  Serial.println("==========================================\n");

  // --- Step 2b: I2C bus scan (diagnostic) ---
  Wire.begin(); // SDA=21, SCL=22
  Serial.println("[I2C] Scanning bus...");
  uint8_t devCount = 0;
  for (uint8_t addr = 1; addr < 127; addr++) {
    Wire.beginTransmission(addr);
    if (Wire.endTransmission() == 0) {
      Serial.printf("[I2C] Device found at 0x%02X", addr);
      if (addr == 0x3C || addr == 0x3D)
        Serial.print(" (SSD1306 OLED)");
      if (addr == 0x68)
        Serial.print(" (DS3231 RTC)");
      if (addr == 0x57)
        Serial.print(" (DS3231 EEPROM)");
      Serial.println();
      devCount++;
    }
  }
  Serial.printf("[I2C] Scan complete: %d device(s) found.\n", devCount);

  // --- Step 2c: OLED Display (early init for boot screen) ---
  displayMgr.initHardware();

  // --- Step 2c: Filesystem ---
  displayMgr.showBootStatus("Montando LittleFS...");
  if (!LittleFS.begin(true)) {
    Serial.println("[LittleFS] Mount Failed. Formatting...");
  } else {
    Serial.println("[LittleFS] Mounted successfully.");
  }

  // --- Step 3: WiFi (must be before NTP/WebServer) ---
  displayMgr.showBootStatus("Conectando WiFi...");
  Preferences wifiPref;
  wifiPref.begin("wifi", true); // true = readonly
  String savedSSID = wifiPref.getString("ssid", String(WIFI_SSID));
  String savedPass = wifiPref.getString("pass", String(WIFI_PASSWORD));
  wifiPref.end();

  Serial.printf("[WiFi] SSID: '%s'\n", savedSSID.c_str());
  Serial.printf("[WiFi] PASS: len=%d\n", savedPass.length());
  Serial.print("[WiFi] Connecting");

  // Add Event Listener to catch specific disconnect reasons
  WiFi.onEvent([](arduino_event_id_t event, arduino_event_info_t info) {
    if (event == ARDUINO_EVENT_WIFI_STA_DISCONNECTED) {
      Serial.printf("\n[WiFi Event] Disconnected! Reason Code: %d\n",
                    info.wifi_sta_disconnected.reason);
    }
  });

  WiFi.mode(WIFI_STA);         // Set STA mode first
  WiFi.disconnect(true, true); // Clean previous connections
  delay(500);

  // Advanced Router Compatibility Fixes (for TIM / Smart Routers)
  WiFi.setSleep(
      false); // Disable sleep for better compatibility with some routers
  WiFi.setAutoConnect(true);
  WiFi.setAutoReconnect(true);

  // Active Scan Workaround: Force the radio to wake up, populate the BSSID
  // cache, and extract the exact BSSID/Channel to avoid Reason 201 (NO AP FOUND
  // / Band Steering)
  Serial.print(" Scanning...");
  int n = WiFi.scanNetworks();
  delay(100);

  uint8_t targetBSSID[6] = {0};
  int32_t targetChannel = 0;
  bool bssidFound = false;

  for (int i = 0; i < n; ++i) {
    if (WiFi.SSID(i) == savedSSID) {
      memcpy(targetBSSID, WiFi.BSSID(i), 6);
      targetChannel = WiFi.channel(i);
      bssidFound = true;
      Serial.printf("\n[WiFi] Found Target BSSID: "
                    "%02X:%02X:%02X:%02X:%02X:%02X on Channel: %d\n",
                    targetBSSID[0], targetBSSID[1], targetBSSID[2],
                    targetBSSID[3], targetBSSID[4], targetBSSID[5],
                    targetChannel);
      break;
    }
  }

  // CRITICAL FIX: To prevent Reason 15 (4-way handshake timeout) on
  // TIM routers we need to set the WiFi config explicitly to disable Protected
  // Management Frames (PMF) because the ESP32 WPA3 implementation sometimes
  // fails to negotiate with modern mixed-mode routers.

  wifi_config_t wifi_config = {};
  strlcpy((char *)wifi_config.sta.ssid, savedSSID.c_str(),
          sizeof(wifi_config.sta.ssid));
  strlcpy((char *)wifi_config.sta.password, savedPass.c_str(),
          sizeof(wifi_config.sta.password));

  // Force WPA2 and Disable PMF completely to bypass the handshake hang
  wifi_config.sta.pmf_cfg.capable = false;
  wifi_config.sta.pmf_cfg.required = false;

  esp_wifi_set_config(WIFI_IF_STA, &wifi_config);

  // Re-attempt standard connection, locking to BSSID and Channel if found
  if (bssidFound) {
    WiFi.begin(savedSSID.c_str(), savedPass.c_str(), targetChannel, targetBSSID,
               true);
  } else {
    WiFi.begin(savedSSID.c_str(), savedPass.c_str());
  }

  {
    int attempts = 0;
    while (WiFi.status() != WL_CONNECTED &&
           attempts < 60) { // Incremented timeout (Reason 39)
      delay(500);
      Serial.print(".");
      attempts++;
    }
  }
  if (WiFi.status() == WL_CONNECTED) {
    Serial.println(" OK!");
    Serial.print("[WiFi] IP: ");
    Serial.println(WiFi.localIP());
  } else {
    Serial.println(" FAILED!");
    Serial.print("[WiFi] Error Code: ");
    switch (WiFi.status()) {
    case WL_NO_SHIELD:
      Serial.println("WL_NO_SHIELD");
      break;
    case WL_IDLE_STATUS:
      Serial.println("WL_IDLE_STATUS");
      break;
    case WL_NO_SSID_AVAIL:
      Serial.println("WL_NO_SSID_AVAIL");
      break;
    case WL_SCAN_COMPLETED:
      Serial.println("WL_SCAN_COMPLETED");
      break;
    case WL_CONNECT_FAILED:
      Serial.println("WL_CONNECT_FAILED");
      break;
    case WL_CONNECTION_LOST:
      Serial.println("WL_CONNECTION_LOST");
      break;
    case WL_DISCONNECTED:
      Serial.println("WL_DISCONNECTED");
      break;
    default:
      Serial.printf("UNKNOWN (%d)\n", WiFi.status());
      break;
    }

    Serial.println("[WiFi] Starting AP mode fallback");
    WiFi.mode(WIFI_AP_STA); // AP + keep trying STA in background
    WiFi.softAP(AP_SSID, AP_PASSWORD);
    Serial.printf("[WiFi] AP started: SSID='%s' PASS='%s'\n", AP_SSID,
                  AP_PASSWORD);
    Serial.print("[WiFi] AP IP: ");
    Serial.println(WiFi.softAPIP());
    // Removed immediate WiFi.begin() because it disrupts the SoftAP network.
  }

  // --- Step 4: Safety Watchdog (sensors) ---
  displayMgr.showBootStatus("Sensores...");
  safety.begin();

  // --- Step 5: Time Manager (RTC + NTP — needs WiFi) ---
  displayMgr.showBootStatus("RTC + NTP...");
  timeMgr.begin();

  // --- Step 5: Fertilizer Manager (NVS state) ---
  fertMgr.begin();

  // --- Step 6: Water Manager (TPA state machine) ---
  waterMgr.begin(&safety, &fertMgr);

  // Load calibrated pump flow rates from NVS
  {
    Preferences calPref;
    calPref.begin("pumpcal", true); // read-only
    float drainLPM = calPref.getFloat("drainLPM", 0);
    float refillLPM = calPref.getFloat("refillLPM", 0);
    calPref.end();
    if (drainLPM > 0) {
      waterMgr.setDrainFlowLPM(drainLPM);
      Serial.printf("[Main] Loaded drain calibration: %.2f L/min\n", drainLPM);
    }
    if (refillLPM > 0) {
      waterMgr.setRefillFlowLPM(refillLPM);
      Serial.printf("[Main] Loaded refill calibration: %.2f L/min\n",
                    refillLPM);
    }
    if (drainLPM <= 0 && refillLPM <= 0) {
      Serial.println(
          "[Main] No pump calibration found. Using safe defaults (30s/15s).");
    }
  }

  // --- Step 7: Web Dashboard + Serial UI ---
  displayMgr.showBootStatus("Web Dashboard...");
  webMgr.begin(&timeMgr, &waterMgr, &fertMgr, &safety, &notifyMgr);

  // --- Step 7b: OLED Display (full init with managers) ---
  displayMgr.begin(&timeMgr, &waterMgr, &fertMgr, &safety, &webMgr);
  displayMgr.showBootStatus("Sistema pronto!", "Iniciando loop...");

  // --- Step 8: Canister filter ON by default ---
  digitalWrite(PIN_CANISTER, LOW); // SSR: LOW = relay ON
  Serial.println("[Main] Canister filter ON (default).\n");

  // --- Step 9: Notifications ---
  notifyMgr.begin();
  notifyMgr.setLanguage(webMgr.getLanguage());

  // --- Step 10: Disable Task Watchdog ---
  // The Arduino framework's task WDT conflicts with our long-running loop
  // (ultrasonic pulseIn blocks ~300ms, I2C transfers, etc). The system already
  // has a comprehensive SafetyWatchdog (sensors, emergency shutdown, overflow
  // detection) so the task WDT is redundant. Disable it to prevent false
  // reboots.
  disableLoopWDT();
  disableCore0WDT();
  Serial.println("[WDT] Task watchdog disabled (SafetyWatchdog active).");

  Serial.println("[Main] === System Ready ===\n");
}

// =============================================================================
// LOOP
// =============================================================================
void loop() {
  // ---- 1. SAFETY (highest priority, runs every 500ms) ----
  safety.update();

  // If in emergency, skip all scheduling and just process commands
  if (safety.isEmergency()) {
    if (!emergencyNotified) {
      notifyMgr.notifyEmergency("Sistema em estado de emergência!");
      emergencyNotified = true;
    }
    webMgr.processSerialCommands();
    webMgr.update(); // keep web server alive
    delay(100);
    return;
  } else {
    emergencyNotified = false;
  }

  // ---- 2. TIME SYNC (periodic NTP re-sync) ----
  timeMgr.update();

  // ---- 3. SERIAL COMMANDS + WEB ----
  webMgr.processSerialCommands();
  webMgr.update(); // handle SSE and HTTP clients

  // ---- 4. WIFI RETRY LOGIC (Every 30 seconds) ----
  if (WiFi.status() != WL_CONNECTED) {
    if (millis() - lastWiFiRetryTime >= WIFI_RETRY_INTERVAL_MS) {
      Serial.println("\n[WiFi] Connection lost/failed. Retrying connection...");

      // If AP is active, we don't want to kill it, just ask STA to reconnect
      WiFi.reconnect();

      lastWiFiRetryTime = millis();
    }
  }

  // ---- 5. SCHEDULING (only if not in maintenance and not running TPA) ----
  if (!safety.isMaintenanceMode()) {

    DateTime now = timeMgr.now();
    uint8_t currentMinute = now.minute();

    // --- Fertilization schedule (Independent per Channel) ---
    fertMgr.update(now);

    // --- Check low stock after fertilization ---
    for (uint8_t ch = 0; ch < NUM_FERTS + 1; ch++) {
      if (fertMgr.isLowStock(ch)) {
        notifyMgr.notifyFertLowStock(ch, fertMgr.getStockML(ch),
                                     fertMgr.getLowStockThreshold(ch));
      }
    }

    // --- Notifications: daily level report + midnight reset ---
    notifyMgr.update(now.hour(), now.minute());
    if (now.hour() == notifyMgr.getDailyReportHour() &&
        now.minute() == notifyMgr.getDailyReportMinute()) {
      float level = safety.getLastDistance();
      notifyMgr.notifyDailyLevel(level);
    }

    // --- TPA schedule ---
    if (currentMinute != lastTPAMinute) {
      tpaDoneThisMinute = false;
      lastTPAMinute = currentMinute;

      // Evaluate interval-based execution
      bool isTPADay = false;
      uint16_t interval = webMgr.getTpaInterval();
      if (interval > 0) {
        unsigned long lastRun = webMgr.getTpaLastRun();
        unsigned long nowEpoch = timeMgr.now().unixtime();

        // 43200 seconds = 12 hours. We grant a 12h leeway so that DST shifts
        // or small clock drifts don't cause it to miss a day. The precise
        // trigger happens below by strictly matching hour and minute.
        if (lastRun == 0 ||
            nowEpoch >= (lastRun + (interval * 86400) - 43200)) {
          isTPADay = true;
        }
      }

      // Determine if a TPA should start (evaluated only once per minute)
      if (!waterMgr.isRunning() && isTPADay) {
        if (timeMgr.isDailyScheduleTime(webMgr.getTpaHour(),
                                        webMgr.getTpaMinute())) {
          if (!webMgr.isTpaConfigReady()) {
            Serial.println("[Main] TPA schedule triggered but config "
                           "incomplete - skipping.");
          } else {
            // Compute dynamic drain/refill targets
            float currentLevel = safety.readUltrasonic();
            float lPerCm = webMgr.getLitersPerCm();
            float aqVol = (float)webMgr.getAquariumVolume();
            float drainLiters = aqVol * webMgr.getTpaPercent() / 100.0f;

            // Cap by reservoir available volume (minus safety margin)
            float resAvail = (float)webMgr.getReservoirVolume() -
                             webMgr.getReservoirSafetyML() / 1000.0f;
            if (resAvail > 0 && drainLiters > resAvail) {
              drainLiters = resAvail;
              Serial.printf("[Main] TPA capped to %.1f L (reservoir limit)\n",
                            drainLiters);
            }

            float cmToDrain = (lPerCm > 0) ? drainLiters / lPerCm : 0;
            waterMgr.setDrainTargetCm(currentLevel + cmToDrain);
            waterMgr.setRefillTargetCm(currentLevel);
            waterMgr.setLitersPerCm(lPerCm); // For inline calibration

            // Compute canister safe level from percentage
            float effH =
                (float)webMgr.getAquariumVolume() / lPerCm; // effective height
            float canisterSafeCm =
                effH * (100.0f - webMgr.getCanisterSafePct()) / 100.0f;
            waterMgr.setCanisterSafeLevelCm(canisterSafeCm);
            waterMgr.setAqEffectiveHeightCm(effH);

            // Dynamic timeouts (if calibrated)
            float drainLPM = waterMgr.getDrainFlowLPM();
            float refillLPM = waterMgr.getRefillFlowLPM();
            if (drainLPM > 0) {
              unsigned long t =
                  (unsigned long)((drainLiters / drainLPM) * 1.5f * 60000.0f);
              waterMgr.setTimeoutDrainMs(t);
              Serial.printf("[Main] Drain timeout: %lums (calibrated)\n", t);
            }
            if (refillLPM > 0) {
              unsigned long t =
                  (unsigned long)((drainLiters / refillLPM) * 1.5f * 60000.0f);
              waterMgr.setTimeoutRefillMs(t);
              Serial.printf("[Main] Refill timeout: %lums (calibrated)\n", t);
            }

            Serial.printf(
                "[Main] TPA: %.1f L = %.1f cm, drain to %.1f, refill to %.1f\n",
                drainLiters, cmToDrain, currentLevel + cmToDrain, currentLevel);
            waterMgr.startTPA();
            webMgr.setTpaLastRun(timeMgr.now().unixtime());
            tpaDoneThisMinute = true;
          }
        }
      }
    }
  }

  // ---- 5. TPA STATE MACHINE ----
  waterMgr.update();

  // If TPA just completed, record timestamp, save calibration, and notify
  if (waterMgr.getState() == TPAState::COMPLETE) {
    waterMgr.setLastTPATime(timeMgr.getFormattedTime());

    // Save calibrated flow rates for next TPA
    if (waterMgr.getDrainFlowLPM() > 0 || waterMgr.getRefillFlowLPM() > 0) {
      Preferences calPref;
      calPref.begin("pumpcal", false);
      if (waterMgr.getDrainFlowLPM() > 0)
        calPref.putFloat("drainLPM", waterMgr.getDrainFlowLPM());
      if (waterMgr.getRefillFlowLPM() > 0)
        calPref.putFloat("refillLPM", waterMgr.getRefillFlowLPM());
      calPref.end();
      Serial.printf("[Main] Calibration saved: drain=%.2f refill=%.2f L/min\n",
                    waterMgr.getDrainFlowLPM(), waterMgr.getRefillFlowLPM());
    }

    if (!tpaCompleteNotified) {
      notifyMgr.notifyTPAComplete();
      tpaCompleteNotified = true;
    }
  } else if (waterMgr.getState() == TPAState::ERROR) {
    if (!tpaErrorNotified) {
      notifyMgr.notifyTPAError(waterMgr.getLastErrorMsg().c_str());
      tpaErrorNotified = true;
    }
  } else if (waterMgr.isRunning()) {
    // Reset flags while TPA is actively running
    tpaCompleteNotified = false;
    tpaErrorNotified = false;
  }

  // ---- 6. WEB DASHBOARD + TELEMETRY ----
  webMgr.update();

  // ---- 7. OLED DISPLAY ----
  displayMgr.update();

  // ---- 8. YIELD ----
  delay(50); // ~20 Hz loop: enough for safety, yields to FreeRTOS IDLE
}

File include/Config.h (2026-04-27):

#pragma once

#include <Arduino.h>

// ============================================================================
// HARDWARE PIN MAPPING
// ============================================================================

// --- MOSFET Channels (Active HIGH) ---
// Fertilizers CH1-CH4
constexpr uint8_t PIN_FERT1 = 13; // CH1 - Fertilizer 1
constexpr uint8_t PIN_FERT2 = 12; // CH2 - Fertilizer 2
constexpr uint8_t PIN_FERT3 = 14; // CH3 - Fertilizer 3
constexpr uint8_t PIN_FERT4 = 27; // CH4 - Fertilizer 4
constexpr uint8_t PIN_PRIME = 26; // CH5 - Prime (dechlorinator)

// TPA Actuators
constexpr uint8_t PIN_DRAIN = 25;    // CH6 - Drain pump
constexpr uint8_t PIN_REFILL = 33;   // CH7 - Refill pump (recalque)
constexpr uint8_t PIN_SOLENOID = 32; // CH8 - Solenoid valve

// Filtration
constexpr uint8_t PIN_CANISTER = 2; // Relay SSR for canister filter

// --- Sensors ---
constexpr uint8_t PIN_TRIG = 18; // Ultrasonic JSN-SR04T trigger
constexpr uint8_t PIN_ECHO = 34; // Ultrasonic JSN-SR04T echo
constexpr uint8_t PIN_OPTICAL =
    4; // Capacitive max-level sensor XKC-Y25-NPN (INPUT_PULLUP, active LOW)
constexpr uint8_t PIN_FLOAT =
    5; // Horizontal float switch reservoir (INPUT_PULLUP, active LOW)
// --- TFT Display (ST7735, SPI) ---
// Board pins: VCC, GND, CS, RESET, A0, SDA, SCK, LED
constexpr uint8_t PIN_TFT_CS = 15;   // CS   — Chip Select
constexpr uint8_t PIN_TFT_DC = 17;   // A0   — Data/Command
constexpr uint8_t PIN_TFT_MOSI = 23; // SDA  — SPI Data
constexpr uint8_t PIN_TFT_SCK = 16;  // SCK  — SPI Clock
constexpr int8_t PIN_TFT_RST = -1;   // RESET — Tied to ESP32 EN

// --- Navigation Button ---
constexpr uint8_t PIN_BTN = 19; // Panel button (INPUT_PULLUP, active LOW)

// --- Display ---
constexpr unsigned long DISPLAY_TIMEOUT_MS = 30UL * 1000; // 30s auto-off

// --- I2C (DS3231 RTC) ---
// Using ESP32 default I2C: SDA=21, SCL=22

// ============================================================================
// ALL OUTPUT PINS (for batch initialization)
// ============================================================================
constexpr uint8_t OUTPUT_PINS[] = {PIN_FERT1,  PIN_FERT2,    PIN_FERT3,
                                   PIN_FERT4,  PIN_PRIME,    PIN_DRAIN,
                                   PIN_REFILL, PIN_SOLENOID, PIN_CANISTER};
constexpr uint8_t NUM_OUTPUT_PINS =
    sizeof(OUTPUT_PINS) / sizeof(OUTPUT_PINS[0]);

// Fertilizer pin array for indexed access
constexpr uint8_t FERT_PINS[] = {PIN_FERT1, PIN_FERT2, PIN_FERT3, PIN_FERT4};
constexpr uint8_t NUM_FERTS = 4;

// ============================================================================
// TIMING & SAFETY CONSTANTS
// ============================================================================

// Pump timeouts
constexpr unsigned long TIMEOUT_DRAIN_MS = 5UL * 60 * 1000;         // 5 min
constexpr unsigned long TIMEOUT_FILL_MS = 10UL * 60 * 1000;         // 10 min
constexpr unsigned long TIMEOUT_REFILL_MS = 10UL * 60 * 1000;       // 10 min
constexpr unsigned long TIMEOUT_PRIME_MS = 60UL * 1000;             // 1 min
constexpr unsigned long TIMEOUT_FERT_MS = 30UL * 1000;              // 30 sec
constexpr unsigned long TIMEOUT_EMERGENCY_MS = 3UL * 60 * 1000;     // 3 min
constexpr unsigned long MAINTENANCE_DURATION_MS = 30UL * 60 * 1000; // 30 min

// Volumes and flow
constexpr float DEFAULT_DOSE_ML = 5.0f;      // Default dose per fertilizer
constexpr float DEFAULT_PRIME_ML = 10.0f;    // Default Prime dose
constexpr float DEFAULT_STOCK_ML = 500.0f;   // Default bottle size
constexpr float FLOW_RATE_ML_PER_SEC = 1.5f; // Peristaltic pump flow rate
constexpr float DEFAULT_DRAIN_PCT = 30.0f;   // Drain 30% of tank

// -- NTP sync interval --
constexpr unsigned long NTP_SYNC_INTERVAL_MS = 24UL * 3600 * 1000; // 24 h

// -- Ultrasonic --
constexpr float ULTRASONIC_MAX_DISTANCE_CM = 400.0f;
constexpr uint8_t ULTRASONIC_SAMPLES = 5; // Median filter samples
constexpr unsigned long ULTRASONIC_PULSE_TIMEOUT_US =
    30000; // 30 ms echo timeout

// -- Water levels (distance from sensor in cm — lower distance = higher water)
constexpr float LEVEL_SAFETY_MIN_CM = 5.0f;     // Overflow alert
constexpr float LEVEL_DRAIN_TARGET_CM = 20.0f;  // Default TPA drain target
constexpr float LEVEL_REFILL_TARGET_CM = 10.0f; // Default refill setpoint

// -- TPA defaults --
constexpr uint8_t DEFAULT_TPA_DAY = 0; // Sunday
constexpr uint8_t DEFAULT_TPA_HOUR = 10;
constexpr uint8_t DEFAULT_TPA_MINUTE = 0;
constexpr uint8_t DEFAULT_FERT_HOUR = 9;
constexpr uint8_t DEFAULT_FERT_MINUTE = 0;

// -- Loop timing --
constexpr unsigned long TELEMETRY_INTERVAL_MS = 10000;  // 10s
constexpr unsigned long SAFETY_CHECK_INTERVAL_MS = 500; // 500ms

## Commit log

2026-02-24 feat: firmware completo ESP32 - TPA, Fertilização e Filtração
    - Config.h: mapeamento de pinos e constantes
    - SafetyWatchdog: sensor ultrassônico (filtro mediana), óptico, emergência
    - TimeManager: RTC DS3231 + NTP com fallback
    - WaterManager: state machine TPA 6 estados com timeout dinâmico
    - FertManager: dosagem diária com dedup NVS (anti-sobredosagem)
    - RainMakerManager: interface Serial + estrutura RainMaker cloud
    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
2026-02-24 test: 59 unit tests nativos para todas as classes do firmware
    - test/mocks/: Arduino mock layer completo (GPIO tracking, millis, NVS, RTClib, NTP)
    - test_fert_manager: 13 testes (dedup NVS, estoque, persistência, GPIO)
    - test_safety_watchdog: 14 testes (sensores, emergência, manutenção, ultrassônico)
    - test_water_manager: 17 testes (state machine TPA completa, abort, timeout, ciclo)
    - test_time_manager: 15 testes (DateTime, agendamento diário/semanal, formatação)
    - fix: drain pump activation em WaterManager (digitalRead ao invés de timing)
    - platformio.ini: [env:native] para testes nativos x86
    Rodar: pio test -e native
    [Arduino.cpp, WaterManager.cpp]
2026-02-24 docs: README com coverage + CI GitHub Actions
    - README.md: badge CI, tabela coverage, arquitetura, pinout, comandos
    - .github/workflows/test.yml: roda testes nativos + build ESP32 a cada push/PR
2026-02-25 refactor: prepara RainMaker para compilação via Arduino IDE
    - RainMakerManager.h: includes RMakerDevice/Param/QR no ifdef
    - RainMakerManager.cpp: printQR() para QR code no Serial monitor
    - platformio.ini: documenta incompatibilidade PlatformIO (issue #8554)
    - Build PlatformIO (sem RainMaker) + 59 testes nativos: OK
2026-02-25 feat: replace RainMaker with Blynk IoT for mobile app control
    - Add BlynkManager.h with 25 virtual pin definitions (V0-V24)
    - Add BlynkManager.cpp with Blynk callbacks, auto-sync, push notifications
    - Update platformio.ini: add blynkkk/Blynk lib, USE_BLYNK flag, WiFi defines
    - Refactor main.cpp to use BlynkManager instead of RainMakerManager
    - Serial command interface preserved (works with/without Blynk)
    - NVS persistence for schedule params (fert/TPA times)
    - Push notifications: emergency, TPA complete, stock low
    - Build: RAM 14%, Flash 62% | 59 native tests pass
    [main.cpp]
2026-02-25 fix: resolve boot crash, make RTC optional, fix WiFi init order
    - Move WiFi.begin() to main.cpp setup() BEFORE TimeManager (NTP needs WiFi)
    - Use Blynk.config() + Blynk.connect() instead of Blynk.begin()
    - Make NTP calls resilient: guard behind WiFi.status() check
    - Lazy-start NTP when WiFi connects after boot
    - Cache NTP epoch in now() to prevent DNS error spam
    - Add default_envs = esp32dev (fix pio run building all envs)
    - Move Blynk credentials to platformio.ini build flags
    - 59 native tests pass
    [TimeManager.cpp, main.cpp]
2026-02-25 fix: eliminate DNS errors by guarding Blynk behind WiFi check
    - Guard Blynk.run() and Blynk.connect() behind WiFi.status() == WL_CONNECTED
    - Defer Blynk connection to update() loop when WiFi comes up
    - Add WiFi SSID/password debug print at boot for diagnostics
    - No more hostByName() DNS failures when WiFi is down
    [main.cpp]
2026-02-25 feat: replace Blynk with embedded web dashboard
    - Add WebManager with ESPAsyncWebServer (REST API + SSE)
    - Add responsive dark-mode HTML dashboard (web_dashboard.h)
    - Real-time telemetry via Server-Sent Events
    - REST endpoints: /api/status, /api/tpa/start, /api/tpa/abort,
    /api/maintenance/toggle, /api/schedule, /api/dose, /api/stock/reset
    - Preserve serial command interface
    - NVS persistence for schedule parameters
    - Delete BlynkManager.h and BlynkManager.cpp
    - Update platformio.ini (ESPAsyncWebServer replaces Blynk)
    - Build: RAM 14.1%, Flash 65.9%
    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
    [WebManager.cpp, main.cpp]
2026-02-25 chore: remove RainMaker and all Blynk/RainMaker references
    - Delete RainMakerManager.h and RainMakerManager.cpp
    - Remove RainMakerManager.cpp from native/coverage build filters
    - Update comments in FertManager.h, WaterManager.h (RainMaker → WebManager)
    - Update README.md architecture and file structure
2026-02-25 fix: add WiFi AP fallback + fix PROGMEM serving
    - When STA fails, ESP32 creates 'AquariumController' hotspot (AP mode)
    - Dashboard accessible at 192.168.4.1 on AP, or router IP on STA
    - Use send_P() for PROGMEM HTML to serve reliably from flash
    - Escape ! in WiFi password to prevent shell mangling
    - AP_STA mode keeps retrying router WiFi in background
    [WebManager.cpp, main.cpp]
2026-02-25 feat: auto-detect disconnected sensors, skip safety checks
    - Track consecutive ultrasonic read failures (10 = disconnected)
    - Skip overflow/emergency checks when sensors not connected
    - Block TPA start when sensors disconnected
    - Initial sensor probe in begin() to detect at boot
    - areSensorsConnected() public method for other modules
    - Log sensor connect/disconnect state changes
    - Fix tests: set valid mock_pulseIn_value before begin()
    - 59/59 tests pass
    [SafetyWatchdog.cpp, WaterManager.cpp, test_safety_watchdog.cpp]
2026-02-25 fix(wifi): prevent STA retry from disrupting AP mode, show correct IP
    [WebManager.cpp, main.cpp]
2026-02-25 fix(wifi): improve ESP32 connection stability on 2.4GHz routers
    [main.cpp]
2026-02-25 feat(wifi): add network scanner and detailed connection error logging
    [WebManager.cpp, main.cpp]
2026-02-25 fix(wifi): apply advanced router compatibility measures to prevent TIM router disconnect reasons 2 & 39
    [main.cpp]
2026-02-25 fix(wifi): disable PMF and force WPA2 via esp_wifi.h to prevent 4-way handshake timeout (Reason 15) on TIM routers
    [main.cpp]
2026-02-25 fix(wifi): extract explicit BSSID and channel to connect directly to MAC to bypass TIM router band steering and Reason 201
    [main.cpp]
2026-02-25 feat(ui): Material Design overhaul and Ferts Weekly Matrix
    - Replaced old Blynk logic with Embedded WebManager serving React SPA
    - Refactored whole UI to Material Design 3 (Dark Theme + Roboto)
    - FertsTab now shows single-channel tuning with 3s PWM Calibration
    - Implemented Ferts Weekly Schedule Matrix in Dashboard
    - Removed Prime (CH5) from static user scheduling
    [FertManager.cpp, TimeManager.cpp, WebManager.cpp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]
2026-02-25 feat: add aquarium dimensions, TPA percentage config, auto-calculated TPA limits, and mandatory config validation
    - Replace single volume input with A×C×L dimension inputs (cm) in ConfigTab
    - Auto-compute aquariumVolume (L) and litersPerCm from dimensions
    - Add tpaPercent to schedule (default 20%) with computed liters display
    - Remove manual drain/refill cm inputs — TPA limits now auto-calculated
    - At TPA start: compute drainTarget from current sensor level + percentage
    - Cap TPA volume by reservoir available capacity (minus safety margin)
    - Add reservoirSafetyML config for pump submersion protection
    - Add tpaConfigReady validation: TPA blocked until dimensions, reservoir
    volume, and T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
    [WebManager.cpp, main.cpp]
2026-02-27 docs: corrige pinout do README (6 pinos errados vs Config.h/circuito)
    - Ultrassônico TRIG: D5 → D18
    - Ultrassônico ECHO: D18 → D19
    - I2C SDA: D23 → D21
    - I2C SCL: D21 → D22
    - Sensor Óptico: D19 → D4
    - Boia Float: D22 → D5
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2026-03-02 fix: inverte lógica PIN_CANISTER para relé SSR (active-low)
    SSR: LOW = relé ligado, HIGH = relé desligado
    - main.cpp: boot com LOW (canister ON)
    - WaterManager: abortTPA/error → LOW (canister ON segurança)
    - WaterManager: _handleCanisterOff → HIGH (canister OFF durante TPA)
    - WaterManager: _handleCanisterOn → LOW (canister ON após TPA)
    - WaterManager.h: isCanisterOn() == LOW
    - WebManager: canister_on → LOW, canister_off → HIGH
    [WaterManager.cpp]
2026-03-02 docs: adiciona documentação de hardware (HARDWARE.md) e BOM
    HARDWARE.md:
    - Camada 1: Entrada AC (fusível, NTC, filtro EMI, relé SSR)
    - Camada 2: Barramento DC (fonte, LM2596, MOSFET 8ch, banco de caps)
    - Camada 3: Periféricos (8 diodos flyback, divisor tensão ultrassônico)
    - Notas de implementação segura
    BOM.md:
    - Lista completa de 35 componentes por categoria
    - Resumo de quantidades
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2026-03-02 fix: repair native test suite — all 69 tests passing
    - Add LEDC PWM stubs (ledcSetup, ledcAttachPin, ledcWrite) to Arduino mock
    - Add String::operator+ overloads for string concatenation
    - Add Preferences::putString/getString with string store
    - Rewrite test_fert_manager for new update(DateTime) API with dayOfWeek
    - Fix SSR relay assertions in test_water_manager (LOW=ON, HIGH=OFF)
    - Include NotifyManager.cpp in native build with -D UNIT_TEST flag
    - Add missing Preferences.h include in test_notify_manager
    [Arduino.cpp, test_water_manager.cpp]
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2026-03-02 test: add calibration tests and fix Arduino mock digitalRead
    - Add 6 new tests: drain/refill calibration, dynamic timeouts, defaults, isCalibrated
    - Fix Arduino mock: digitalWrite now updates mock_pin_read_value so output
    pins can be read back (needed for pump state checks)
    - Total: 75 tests passing, WaterManager coverage 78% → 92%
    [Arduino.cpp, test_water_manager.cpp]
2026-03-02 docs: add TPA water change flow diagram and step-by-step explanation
    - Add mermaid stateDiagram showing all 6 states + ERROR transitions
    - Add step-by-step table explaining each state (EN, PT-BR, JA)
    - Document safety notes: dynamic timeouts, optical sensor cutoff,
    emergency abort, and auto-calibration
2026-03-02 fix: safe canister recovery on TPA error — check water level first
    - _error() now reads ultrasonic level before turning canister back on
    - If water level is too low (dist > refillTargetCm), canister stays OFF
    to avoid running dry and damaging the pump
    - If no safety sensor available, canister stays OFF (fail-safe)
    - Update TPA flow diagrams in all READMEs (EN/PT-BR/JA)
    [WaterManager.cpp]
2026-03-03 feat(i18n): add multi-language push notifications (PT/EN/JA)
    - Add NotifyStrings.h with string tables for 14 notification messages × 3 languages
    - Add _language field to WebManager (NVS persisted, exposed in /api/status)
    - Parse language in /api/schedule endpoint and propagate to NotifyManager
    - Replace all hardcoded PT strings in NotifyManager with NOTIFY_STRINGS[_lang] lookups
    - Propagate language setting from WebManager to NotifyManager on startup
    [NotifyManager.cpp, WebManager.cpp, main.cpp]
2026-03-03 feat(3d): add OpenSCAD parametric models for enclosure and pump supports
    - Electronics enclosure (250×150×60mm):
    - AS-08 IEC C14 with fuse (AC input)
    - NBR 14136 panel outlet (canister)
    - 8× P4 DC barrel jack connectors (pumps)
    - 3× RJ45 connectors (sensors)
    - 40mm fan grille (MOSFET cooling)
    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
    [dosing_pump_single.scad, dosing_pump_support.scad, electronics_enclosure.scad]
2026-03-03 feat(3d): refine enclosure - remove cooler, add wall mounts, update connectors
    Changes:
    - Removed 40mm cooler fan (unnecessary for MOSFET thermal load)
    - Added wall mounting tabs on left/right sides with 4.5mm screw holes
    - Updated AC IN cutout to AS-08A tripolar (31.2×27.2mm snap-in)
    - Updated CANISTER cutout to NBR 14136 snap-in (40.5×21.7mm, rotated 90°)
    - Changed CAP sensor connector from RJ45 to JST XH 3-pin (8×6mm)
    - Increased bottom ventilation slots from 4 to 8
    - Added 3 horizontal vent slots on back panel for PSU convection
    - Removed PSU screw pillars (mounted with double-sided tape)
    - Fixed sensor label orientation (right-side-up, below holes)
    - Aligned AC IN / CANISTER label p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
    [electronics_enclosure.scad]
2026-03-03 feat(firmware): rewrite OLED display for 128x32, add I2C scan, improve boot flow
    Display:
    - Rewrite all 4 OLED pages for 128x32 form factor (was 128x64)
    - Page 3 (Fert): vertical bar chart with rotated percentage labels
    - Compact layout with optimized spacing for small screen
    - Add initHardware() for early boot screen before managers init
    - Add showBootStatus() for step-by-step boot progress on OLED
    Boot sequence:
    - Add I2C bus scan diagnostic at startup (detects SSD1306, DS3231)
    - Show boot progress on OLED: LittleFS, WiFi, Sensors, NTP, Web
    - Move display hardware init before WiFi for visual feedback
    Safety & stability:
    - Add yield() in ultrasonic sampling loop to prevent task WDT trigge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
    [DisplayManager.cpp, SafetyWatchdog.cpp, main.cpp]
2026-03-04 feat(firmware): migrate display from SSD1306 OLED to ST7735 TFT
    - Replace SSD1306 (I2C, 128×32, mono) with ST7735 (SPI, 128×160, RGB)
    - Full color TFT UI: accent headers, color-coded bars, status indicators
    - Conditional compile: #ifdef USE_SSD1306 keeps Wokwi working with OLED
    - Guard TPA/FERT buttons with #ifdef WOKWI_TEST (GPIO 15/23 → SPI pins)
    - Add color palette: cyan accent, green/yellow/red status, dark gray bars
    - Update platformio.ini: ST7735 lib for esp32dev, SSD1306 flag for wokwi
    - Update all 3 READMEs (pt-BR, EN, JA) with new display and SPI wiring
    [Config.h, DisplayManager.cpp, main.cpp]
2026-03-04 refactor: remove Wokwi simulation + add ESP32 GPIO connection diagram
    - Remove [env:wokwi] from platformio.ini (ST7735 incompatible with Wokwi)
    - Remove diagram.json and wokwi.toml
    - Remove #ifdef WOKWI_TEST guards: buttons, fast timing overrides
    - Remove #ifdef USE_SSD1306 fallback — DisplayManager is now ST7735-only
    - Simplify Config.h: only production timing values remain
    - Clean main.cpp: remove all Wokwi button handling code
    - Remove Wokwi sections from all 3 READMEs (pt-BR, EN, JA)
    - Add detailed ESP32 GPIO connection table to all 3 READMEs
    showing 21 pins with function, component, direction, and protocol
    [Config.h, DisplayManager.cpp, main.cpp]
2026-03-04 docs: fix TFT pin labels to match board silkscreen (CS, SCK, SDA, A0, RESET, LED)
    - Update Config.h comments with board pin names alongside function names
    - Fix GPIO connection table in all 3 READMEs (pt-BR, EN, JA)
    - Add LED (backlight → 3.3V) and RESET (→ ESP32 EN) rows
    - Rename: DC→A0, MOSI→SDA, Clock→SCK to match physical labels
    [Config.h]
2026-03-04 fix(display): show water level as percentage + translate header fallback
    - Aquarium page: show water level as percentage instead of raw cm
    - Header fallback: 'Nivel: --' → 'Level: --' (language-neutral)
    [DisplayManager.cpp]
2026-03-05 fix(notify): fix cooldown never being set — caused notification spam
    Root cause: _send() never received the NotifyType, so _lastNotifyMs[type]
    was never set after a successful send. Cooldown check in _canSend() always
    passed, causing duplicate notifications for every call during the matching
    minute window.
    Fix: pass NotifyType to _send(), set _lastNotifyMs[type] = millis() after
    successful delivery (both UNIT_TEST and production paths).
    [NotifyManager.cpp]
2026-03-05 fix(display): make clock seconds tick in real-time
    Separate page redraw timer (1s) from page switch timer (5s).
    Previously the display only refreshed when switching pages, so
    the clock seconds appeared frozen. Now all pages redraw every
    second for live data updates.
    [DisplayManager.cpp]
2026-03-05 fix(display): zero-flicker clock using setTextColor(fg, bg)
    Replace fillRect + setTextColor(fg) with setTextColor(fg, bg).
    Adafruit GFX draws background behind each character pixel in a
    single SPI pass, eliminating the visible black flash entirely.
    [DisplayManager.cpp]
2026-03-05 feat(display): flicker-free aquarium page with live partial redraws
    - Add _drawAquariumPageLive() for 1s partial updates of:
    water level %, TPA state, canister ON/OFF status
    - Uses setTextColor(fg, bg) for zero-flicker text overwrite
    - Padded text formatting prevents ghost characters
    - Active during TPA lock and normal carousel
    [DisplayManager.cpp]
2026-03-05 feat(display): eliminate page transition flicker — header stays solid
    - Replace fillScreen() with fillRect on content area only (y=24..128)
    - Header (accent bar + level bar + separator) persists across pages
    - New _drawHeaderTitle() uses setTextColor(fg, bg) on accent bar
    to overwrite title without flicker, padded to 12 chars
    - Zero visual disruption on page carousel transitions
    [DisplayManager.cpp]
2026-03-08 feat: per-day schedule times + compact fertilizer cards
    Backend:
    - FertManager: _schedHour/Minute expanded to [ch][7] per day-of-week
    - WebManager: status JSON sends sH/sM as arrays, API accepts hours[]/minutes[]
    - NVS: per-day keys (sH{ch}_{day}) with backward compat from legacy single keys
    Frontend:
    - FertConfigModal: per-day HH:MM inputs (only shown when dose > 0)
    - FertsTab: redesigned compact cards with mini schedule table + footer buttons
    - HomeTab: per-day times shown under each dose in weekly table
    - App.tsx: AQStatus type updated (sH/sM -> number[])
    [FertManager.cpp, WebManager.cpp]
2026-03-08 fix: update canister outlet cutout to Margirius snap-in dimensions
    - Renamed nbr_outlet_d (circular) to canister_outlet_w/h (40.5x21.7mm rectangular)
    - Updated both 3D and laser files to use named parameters
    - Matches Margirius Brazilian standard power inlet datasheet
    [electronics_enclosure_3d.scad, electronics_enclosure_laser.scad]
2026-03-08 feat: single-button display navigation (GPIO 0)
    - PIN_BTN = GPIO 0 (BOOT button) with INPUT_PULLUP
    - Short press: wake display / next page
    - Long press (3s): open menu
    - Menu items: Start TPA, Toggle Maintenance
    - Display auto-off after 30s of inactivity
    - Button debounce (50ms) + edge detection
    - Menu auto-close after 5s inactivity
    - i18n menu strings (PT/EN/JA)
    [Config.h, DisplayManager.cpp]
2026-03-08 refactor: replace RJ45 sensor connectors with GX12 aviation plugs
    - RJ45 rectangular cutouts (16x14mm) -> GX12 circular holes (12mm)
    - Simplified front panel with parametric loop for 3 GX12 connectors
    - Updated both 3D and laser files
    - Adjusted labels and button positioning
    [electronics_enclosure_3d.scad, electronics_enclosure_laser.scad]
2026-03-13 feat(enclosure): atualizar dimensões reais e layout dos módulos
    - PSU: 165×97.4mm (medido)
    - ESP32 MRD068A: 63×69mm, furos 58×64.5mm, posição [40,65]
    - MOSFET: furos 90×43mm (medido)
    - LM2596: 65.7×35.7mm, furos 60×30.7mm, posição [-20,33]
    - RTC DS3231: 38×21.7mm, 3 furos (sem canto sup-esq)
    - TFT: tela 38.5×32mm, placa 58×34.4mm, furos 51.5×28mm
    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
    [electronics_enclosure_3d.scad, electronics_enclosure_laser.scad]
2026-03-13 feat(enclosure): atualizar medidas reais ULTRA, SSR e render all_2d
    - ULTRA: placa 41.5×28.5mm, furos 36×23.5mm (medido)
    - SSR: placa 34.1×25.1mm, furos 29×19.5mm, posição [92,28]
    - Sincronizado dimensões no arquivo 3D
    - Ativado all_2d() como render padrão
    [electronics_enclosure_3d.scad, electronics_enclosure_laser.scad]
2026-03-16 fix(enclosure): corrigir dimensões e posições dos módulos ESP32, SSR e RTC
    - ESP32: espaçamento dos furos de 58mm para 58.5mm (esp32_w: 63→63.5)
    - SSR: girado 90° e reposicionado (Y=17.5) para alinhar furos inferiores
    - RTC: largura corrigida para 30.5mm (furos horizontais: 25.5mm)
    - SSR e RTC alinhados com MOSFET/LM2596 nos furos inferiores (Y≈3)
    [electronics_enclosure_3d.scad, electronics_enclosure_laser.scad]
2026-03-17 feat(enclosure): RTC com 4 furos e cantoneiras nos recortes dos painéis
    - RTC: alterado de 3 para 4 furos simétricos (permite rotação livre)
    - Threshold de standoffs reduzido de 35mm para 20mm (RTC e SSR com 4 furos)
    - Cantoneiras de apoio movidas para dentro dos recortes existentes:
    2 no canister, 1 no AC IN, 1 no display TFT (otimiza material)
    [electronics_enclosure_3d.scad, electronics_enclosure_laser.scad]
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2026-03-30 feat(enclosure): split lid horizontally, redesign mid-support, add engravings layer
    Lid:
    - Split lid into lid_front_2d (handle + vents) and lid_back_2d (TFT + IARA logo)
    - Added magnet holes at split line on both halves
    - Added SVG logo and IARA text to back lid left area
    Mid-support:
    - Replaced L-tab design with compact 15x30mm double-square piece
    - Added finger joint tabs on one side for panel attachment
    - Added finger joint slots on left/right lateral panels
    - 2 magnet holes aligned with lid split line magnets
    Component adjustments:
    - ESP32 rotated 90 degrees (both 3D and laser files)
    - CH5-8 pump spacing adjusted (col_spacing=22)
    - SSR rotated 90 degrees and aligned with RTC
    Engraving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
    [electronics_enclosure_3d.scad, electronics_enclosure_laser.dxf, electronics_enclosure_laser.scad]
2026-03-30 refactor(enclosure): remove MAG, BTN, TFT text labels
    - Removed MAG labels from corner_support_2d and mid_support_2d
    - Removed BTN label from base_2d_right panel
    - Removed TFT label from lid_back_2d
    - Updated all_2d_engravings to match
    [electronics_enclosure_laser.dxf, electronics_enclosure_laser.scad]
2026-03-30 fix(enclosure): fix sensor label alignment in engravings module
    - Added missing gx12_spacing local definition (gx12_d + 10)
    - Fixed sensor_z_2d to use psu_h - 4 matching base_2d_front()
    - Enabled both all_2d and all_2d_engravings for overlay verification
    [electronics_enclosure_laser.scad, electronics_enclosure_laser_textos.dxf]
2026-04-06 feat(3d_models): add snap-fit titanium electrodes support and laser enclosure updates
    [electrodes_support.scad, electrodes_support.stl, electronics_enclosure_laser.dxf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]
2026-04-06 docs(hardware): simplify Layer 1 AC diagram and fix dangerous relay logic
2026-04-07 docs(hardware): replace RJ45 with robust GX12 aviation connectors and update MOSFET decoupling capacitor
2026-04-08 feat: design do suporte de bombas ajustado para corte a laser em MDF 3mm (layout 40x60)
    [dosing_pump_support_laser.scad, dosing_pump_support_laser_3mm.dxf]
2026-04-09 feat: ajusta vão de mangueira para 23mm atrás dos furos M3 e adiciona peça de teste de furação
    [dosing_pump_support_laser.scad, dosing_pump_support_laser_3mm.dxf, pump_shelf_test.dxf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]
2026-04-13 fix(display): corrige rotação do ST7735 e documenta wiring completo
    - Altera setRotation(1) → setRotation(3) para corrigir orientação
    180° invertida no display TFT ST7735
    - Adiciona tabela de pinagem SPI do display ST7735 (VCC, GND, CS,
    RESET→EN, DC, MOSI, SCK, LED) em HARDWARE.md e HARDWARE.en.md
    - Documenta que o pino RESET do display deve ir ao EN do ESP32
    - Adiciona esquema de ligação do botão de navegação (GPIO0/BOOT)
    [DisplayManager.cpp]
2026-04-13 feat(hardware): aumenta largura dos painéis laterais do suporte de eletrodos (+13mm)
    [electrodes_support.scad, electrodes_support.stl]
2026-04-13 feat(hardware): adiciona suporte de bombas dosadoras para corte a laser
    Suporte modular para 4 bombas dosadoras e 4 frascos Seachem 500ml,
    otimizado para chapa MDF 400×600mm com juntas de encaixe.
    [dosing_pump_support_laser.dxf]
2026-04-13 chore(cleanup): remove arquivos obsoletos de enclosure laser
    [electronics_enclosure_laser.dxf, electronics_enclosure_laser_texto.dxf, electronics_enclosure_laser_textos.dxf]
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2026-04-27 feat(hardware): swap ultrasonic ECHO to GPIO34 and button to GPIO19
    [Config.h]
